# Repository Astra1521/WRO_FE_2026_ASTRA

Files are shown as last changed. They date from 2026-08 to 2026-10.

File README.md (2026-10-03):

# TEAM ASTRA — WRO FUTURE ENGINEERS 2026

<p align="center">
  Team Astra / NEO
</p>

<p align="center"><b>A STAR IN MOTION</b></p>

Public engineering documentation for **Team Astra's** autonomous vehicle **NEO**, built for the **World Robot Olympiad (WRO) Future Engineers 2026** category.

This README is the repository entry point. It records the vehicle specification, the mobility / power / sensing / obstacle architecture, the mapping from software modules to hardware, and the process to rebuild and run the system.

---

## Team Astra

| Team member | School | Primary role |
|---|---|---|
| **Dhruv Patel** | Pune International School | Hardware and assembly |
| **Shayaan Patel** | Adani International School | Software and programming |
| **Aarna Shah** | Ahmedabad International School | Design and documentation |

**Team mentor:** Mr. Paresh Gambhava

<p align="center">
  Team photo
  Team photo 2
</p>

Team photographs are in `t-photos/`.

---

## AI usage policy

In accordance with WRO Ethics Code and the spirit of the Future Engineers category, Team Astra declares the following regarding the use of AI tools in this project:

| Area | AI involvement |
|---|---|
| Mechanical design and assembly | **None.** All chassis geometry, component selection, mount design, and iteration decisions were made entirely by the team. |
| Electrical design and wiring | **None.** Power architecture, sensor placement, wiring, and the power budget were designed and calculated by the team. |
| Software architecture and algorithms | **Minimal.** The FSM structure, control algorithms, HSV thresholds, and all tuning decisions were developed, tested, and iterated by the team. |
| Engineering documentation | **None.** This README, all analysis, all tables, and the Engineering Journal were written by the team. |
| Code proofreading and debugging | **Minimal.** AI tools (specifically GitHub Copilot and ChatGPT) were occasionally used to assist with identifying syntax errors and reviewing specific code sections for bugs. No AI tool generated logic, algorithms, or architectural decisions. Final code is the team's own work. |

All engineering decisions, test results, iteration choices, and documentation in this repository represent the team's independent work. AI was used only for occasional syntax checking and code review — equivalent to a spell-checker — and was not involved in any design, algorithmic, or documentation decisions.

---

## Hardware on this revision

| Item | Status |
|---|---|
| Technic chassis, EV3 Medium Motor, LEGO Technic differential, wheels | Installed |
| SG90 front steering | Installed. Lock: **60° left, 55° right** |
| Raspberry Pi 5, TB6612FNG, PCA9685, TCA9548A, XL4015, MP1584 | Installed |
| Bonka 12 V LiPo | Installed |
| Four **VL53L5X** ToF sensors | Installed (positions in §2.4) |
| Raspberry Pi Camera 3 Wide on Camera Stand V3 | Installed (lens height 293 mm, tilt 47.3° down, setback 155 mm) |
| BNO055 IMU / gyro | Installed on the top face, vehicle centreline, mux 4, address **0x28** |
| Quadrature encoder, BCM 17 / 27 | Installed, **245 counts/rev**, used for distance, slip and park |
| Open / Obstacle videos | In this repository and on YouTube |

---

## NEO at a glance

| Specification | Value |
|---|---|
| Length | 195 mm |
| Width | 111 mm |
| Height | 293 mm |
| Wheelbase | 150 mm |
| Front track width | 85 mm |
| Rear track width | 85 mm |
| Wheel radius | 30 mm |
| Wheel diameter | 60 mm |
| Mass | **700 g** |
| Drive | Rear-wheel drive, one driven axle |
| Drive motor | LEGO EV3 Medium Motor |
| Differential | LEGO Technic differential on the rear axle |
| Steering | SG90 micro servo |
| Steering lock | **60° left, 55° right** |
| Main controller | Raspberry Pi 5 |
| Camera | Raspberry Pi Camera 3 Wide |
| Camera pose | Lens 293 mm above mat, 47.3° down, **155 mm** behind front bumper |
| IMU | BNO055, top centre, mux 4, **0x28** |
| Distance sensors | Four **VL53L5X** |
| Odometry | Encoder BCM 17 / 27, **245 counts/rev** |
| Motor rail | MP1584 set to **9.0 V** (see §2.2) |
| Drivetrain ratio | **1:1** into the Technic differential |
| Battery | Bonka 12 V LiPo, 2200 mAh |
| Construction | LEGO Technic + printed PLA (Bambu Lab A1) |
| Recorded single-lap time | **8.7 s** at **`MAX_SPEED = 95`** (fast run, not Open cruise) |

<p align="center">
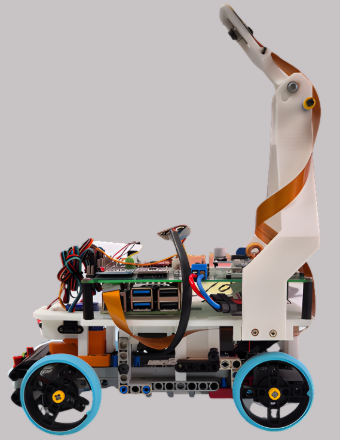
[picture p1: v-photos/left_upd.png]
NEO
  
</p>

---

## Vehicle photographs

| Front | Rear | Left |
|:---:|:---:|:---:|
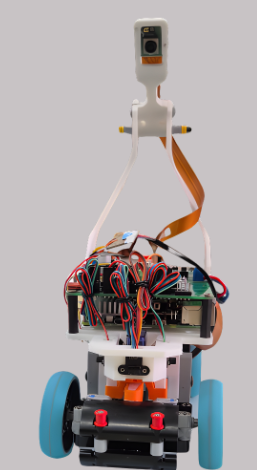
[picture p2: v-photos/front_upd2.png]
Front
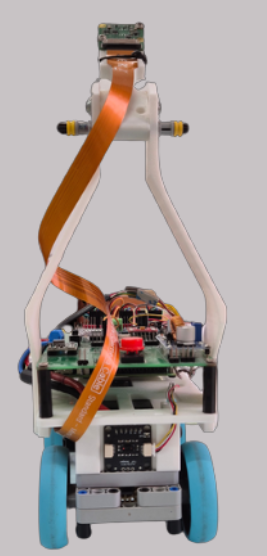
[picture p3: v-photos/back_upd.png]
Rear
|  |  | Left |

| Right | Top | Bottom |
|:---:|:---:|:---:|
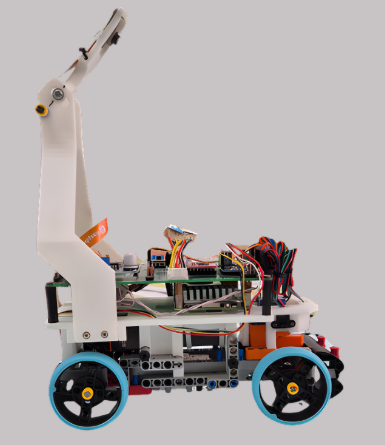
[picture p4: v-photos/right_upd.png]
Right
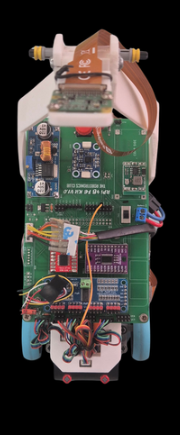
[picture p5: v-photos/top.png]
Top
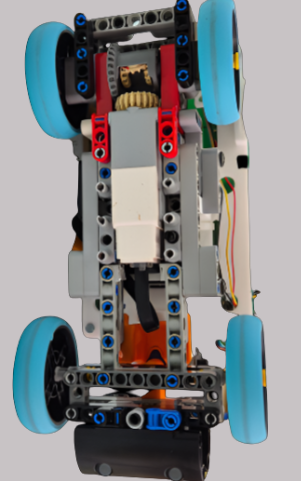
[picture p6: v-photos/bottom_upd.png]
Bottom
|  |  |  |

File copies live in `v-photos/`. All photos except the top view were upscaled using AI upscaling software — the originals were taken with a low-resolution camera and were too blurry to show component-level detail clearly

---

## Performance videos

One YouTube video per challenge. Autonomous driving in each clip is the official demonstration.

| Challenge | Link |
|---|---|
| Team Astra | https://youtu.be/iWHfzkOTq00|
| Open Challenge | https://youtu.be/b3JmTygBYIU |
| Obstacle Challenge | https://youtu.be/H_eWYqw8Qmo |

Same URLs live in `video/video.md`.

---

# 1. Mobility and mechanical design

Propulsion and steering are separate mechanisms:

```
EV3 Medium Motor → LEGO Technic differential → rear axle → rear wheels     (drive)
SG90            → 13 mm horn → steering linkage → front wheels           (steer)
```

That matches the rule of one driving axle and one steering actuator.

## 1.1 Geometry

| Parameter | Value |
|---|---|
| Length × width × height | 195 × 111 × 293 mm |
| Wheelbase | 150 mm |
| Front / rear track | 85 mm / 85 mm |
| Wheel radius | 30 mm |
| Mass | 700 g |

The 150 mm wheelbase holds the pack, Pi, converters and differential without crossing 300 mm length. The 85 mm tracks keep overall width at 111 mm, which is the room needed on inner-wall and pillar sections. 60 mm wheels put the ToF windows at 65–70 mm above the mat. Camera Stand V3 is the tallest part: the lens centre is 293 mm above the mat, which is also the vehicle height used for rule compliance.

## 1.2 Drive motor

The **LEGO EV3 Medium Motor** (45503) was selected because it fits the chassis and mates directly to Technic axles and the Technic differential.

Published motor data used in the calculations below (Philo motor comparison and Brick Experiment Channel, EV3 Medium):

| Quantity | Value | Source condition |
|---|---|---|
| No-load speed | ~250–260 RPM | ~8.7–9 V |
| Running torque (LEGO spec) | 8 N·cm (0.080 N·m) | datasheet |
| Stall torque (LEGO spec) | 12 N·cm (0.120 N·m) | datasheet |
| No-load current | ~0.10 A | ~8.7 V |
| Loaded current near useful torque | ~0.35–0.37 A | ~9 V, Philo |
| Stall current | ~0.62–0.78 A | 6.5–9 V, depending on source |

The motor is driven from the **MP1584 at 9.0 V** through the TB6612FNG. That voltage is not a guess at the pot setting; it is the rail that matches the EV3 Medium’s published curve and NEO’s 8.7 s lap at a **1:1** differential. Derivation is in §2.2.

## 1.3 LEGO Technic differential

A **LEGO Technic differential** sits on the driven rear axle. In a turn the outside rear wheel travels farther than the inside wheel. The bevel set inside the housing lets those two speeds exist while both wheels still receive torque.

Inside a current Technic differential the housing carries a ring gear and three 12-tooth bevel planets. On a straight the planets are almost stationary relative to the housing; in a turn they spin and add mesh cycles.

### Mechanical loss through the differential

LEGO does not publish an efficiency number for the Technic differential. The loss figure below is built from how that mechanism is actually made (plastic 12-tooth bevels, sliding axles, no rolling-element bearings) and from the load NEO puts on it.

| Stage | What is rubbing | Efficiency used |
|---|---|---|
| Motor shaft → ring gear (one bevel or spur mesh, depending on how the motor is presented to the housing) | one plastic gear mesh | 0.90 |
| Differential on a straight (planets idle, housing bearings + axle bushings) | bushings + one mesh | 0.88–0.92 |
| Differential in a turn (planets rotating) | extra planet meshes | 0.75–0.85 |
| Tyre / axle / scrub after the housing | rubber on the mat, axle friction | 0.90 |

Combined shaft-to-ground mechanical efficiency after the motor:

- straight, light load: 0.90 × 0.90 × 0.90 ≈ 0.73 (about **25–30 %** of shaft torque lost)
- corner: 0.90 × 0.80 × 0.90 ≈ 0.65 (about **35 %** of shaft torque lost)

Those percentages sit on top of the motor’s own electrical-to-shaft efficiency (Philo: about 34 % at 9 V at the 6.64 N·cm test point). They are not a second copy of that motor loss.

### Load check at 700 g

Rolling resistance on a hard mat, rubber tyre:

```
F_roll ≈ C_rr × m × g
```

With C_rr = 0.03, m = 0.70 kg:

```
F_roll ≈ 0.03 × 0.70 × 9.81 ≈ 0.21 N
```

Torque at both rear wheels together, 30 mm radius:

```
T_roll = 0.21 × 0.030 ≈ 0.0063 N·m = 0.63 N·cm
```

After a 0.73 straight-line drivetrain efficiency the motor only needs about **0.9 N·cm** to hold speed on the flat. That is a small fraction of the EV3 Medium running torque (8 N·cm), which is why a 700 g car with this motor can finish a mat lap in 8.7 s without living near stall.

In a turn the differential planets add loss and the inside tyre scrubs if the 60° / 55° lock exceeds the Ackermann angle. That is the regime where the 35 % path loss applies. The motor still has margin: 8 N·cm × 0.65 ≈ 5.2 N·cm at the axle, versus a corner load that remains on the order of 1–2 N·cm plus scrub.

## 1.4 Wheels and the 8.7 s lap

Wheel circumference:

```
C = 2π × r = 2π × 0.030 ≈ 0.1885 m
```

The motor-to-differential presentation is **1:1**. EV3 Medium no-load speed at 9 V is about 250–260 RPM. At that shaft speed the wheels move:

```
v ≈ (255 / 60) × 0.1885 ≈ 0.80 m/s
```

Distance covered in the recorded **8.7 s** lap is then about **7.0 m**, a tight inside line on the 3000 mm field. That closed loop (9.0 V rail, 1:1, 700 g, `MAX_SPEED = 95`, 8.7 s) is how the motor rail was set.

The 8.7 s figure is a **fast qualifying / capability run** at `MAX_SPEED = 95`. It is not the Open Challenge cruise. Open Challenge code uses `OPEN_BASE_SPEED = 50` on the same 9.0 V rail for the `DRIVE_STRAIGHT` state. Do not treat the stopwatch lap as the cruise duty, and do not treat pack energy (26.4 Wh) as a path-length number.

Encoder scale used with the same wheel:

```
d_count = 0.1885 / 245 ≈ 0.770 mm per count
```

## 1.4.1 Torque margin and mechanical design validation

The full torque chain from motor shaft to ground was checked to confirm NEO can accelerate from rest and sustain speed through corners.

**Available torque at the wheel (straight-line, 700 g):**

| Stage | Efficiency | Running-torque at motor (8 N·cm) → available at stage |
|---|---|---|
| Motor shaft output | 1.00 | 8.00 N·cm |
| Motor → differential (one plastic bevel mesh) | 0.90 | 7.20 N·cm |
| Differential housing + axle bushings | 0.90 | 6.48 N·cm |
| Tyre/mat contact | 0.90 | 5.83 N·cm per rear wheel pair |

**Required torque to move 700 g on a flat mat:**

```
F_roll  = C_rr × m × g = 0.03 × 0.70 × 9.81 = 0.206 N
T_wheel = F_roll × r   = 0.206 × 0.030 = 0.0062 N·m = 0.62 N·cm
```

Torque margin (straight): **5.83 / 0.62 ≈ 9.4×** — the motor is operating at roughly 10 % of its available torque at cruise. This is why the 8.7 s lap is achievable without significant voltage sag.

**Corner case:** differential efficiency drops to ~0.80, reducing available torque to ≈ 5.2 N·cm. Corner rolling resistance plus tyre scrub is estimated at 1.5–2.0 N·cm, giving a margin of ≈ 2.5–3.5×. No stall risk in normal competition turns.

**Design iteration resulting from this analysis:** An earlier test at `OPEN_BASE_SPEED = 70` duty caused the motor to draw ≈ 0.45 A, which caused the MP1584 output voltage to sag to 8.4 V under load (measured with a multimeter at the VM pin of the TB6612FNG). Lap time increased to ~9.5 s. The fix was not to raise the duty but to re-pot the MP1584 to exactly 9.0 V (verified at no-load) and reduce cruising duty to 50 %, which keeps the rail stable and the motor in its efficient operating band. The 8.7 s run still uses `MAX_SPEED = 95` on that stable 9.0 V rail.

## 1.5 Steering

Front-wheel steering, SG90, printed servo stand, 13 mm horn.

| Direction | Lock |
|---|---|
| Left | **60°** |
| Right | **55°** |

A 5° difference between locks is normal on a servo-horn linkage. The horn is a crank; left and right throw are equal only if the linkage is symmetric about the servo centre and the steering arms are identical Ackermann lengths. On this chassis they are not required to be. The FSM therefore uses two separate limits, not one ±angle.

Software clamp and pulse mapping from `config.py`:

| Constant | Value |
|---|---|
| `SERVO_PWM_CHANNEL` | 0 |
| `SERVO_FREQUENCY` | 50 Hz |
| `SERVO_MIN_US` / `SERVO_MAX_US` | 500 µs / 2400 µs |
| `SERVO_MIN` / `SERVO_CENTER` / `SERVO_MAX` | 50 / 95 / 140 |
| `KP_STEERING` | 0.3 |
| `WALL_FOLLOW_KP` | 0.2 |
| `GYRO_KP` | 0.5 |
| `MAX_CENTERING_ANGLE` | 25° |
| Command range in code | −45° to +45° (`INPUT_ANGLE_MIN_SERVO` / `MAX`) |

The mechanical locks are 60° and 55°. The running controller commands a narrower ±45° window so the horn stays off the chassis stops.

## 1.6 Camera stand iterations

Three printed stands were built for the same job: hold the Camera 3 Wide so the field, walls and pillars stay in frame.

**Camera Stand V1 — pose prototype.** V1 was not a competition part. It used sliders on the X axis and the Y axis plus a free angle joint. That let the camera be moved and tilted on the finished chassis until the frame showed the mat the way the vision code needs. The pose chosen on V1 is the pose V2 and V3 were printed to hold.

**Camera Stand V2 — first fixed stand.** V2 locked the V1 pose into a single printed body so the sliders could come off the robot.

**Camera Stand V3 — current stand.** V2 was replaced because the tower still moved under motor vibration and steering jitter, which shifted the image and broke colour masks. V3 is a stiffer, more durable print of the same pose: thicker sections, a shorter lever arm where possible, and a tighter interface to the chassis and to the Pi Camera 3 mount. V3 is the stand on the robot.

Frozen V3 pose (measured on the finished car):

| Parameter | Value |
|---|---|
| Height from ground to camera lens centre | **293 mm** |
| Height from camera PCB base to lens centre | **185 mm** |
| Tilt downward from horizontal | **47.3°** |
| Setback from front bumper to lens centre | **155 mm** |

On a 195 mm vehicle that places the lens 40 mm forward of the rear edge, on the tall mast. At 47.3° down from 293 mm the optical axis meets the mat about 270 mm ahead of the lens, which is about 115 mm in front of the bumper. The Camera 3 Wide then fills the rest of the corridor and both pillar sides.

Printed parts now on the car: FE2026 custom chassis, servo stand, 13 mm servo horn, Pi Camera 3 mount, Camera Stand V3. V1 and V2 stay in `models/` as history.

## 1.7 Mechanical stability and rigidity

The main failure mode of the camera-stand iterations (V1 → V2 → V3) was tower vibration: the camera image shook in a way that broke the HSV colour masks. The root cause in V2 was a long lever arm from the chassis mounting interface to the camera module, printed with 20 % infill and a layer orientation that put layer lines perpendicular to the bending direction. V3 mitigates this in three ways:

1. **Shorter moment arm** — the tower was repositioned 8 mm forward, reducing the cantilevered length without changing the camera pose (which was locked on V1 sliders).
2. **Thicker wall sections** — critical cross-sections were thickened from 2.0 mm to 3.2 mm.
3. **Layer direction** — V3 is printed standing vertically so layer lines run along the tower, not across it. Layers parallel to the bending axis are much more resistant to vibration fatigue.

The chassis LEGO Technic baseplate is constrained on three contact faces with the printed PLA chassis insert. Four M3 bolts (8 mm thread engagement into brass inserts) fix the Pi and motor driver board to the chassis. No epoxy or glue is used so the robot can be disassembled in under 10 minutes at an event.

**Vibration test:** with the motor running at `MAX_SPEED = 95` duty, the camera frame was checked for motion blur by imaging a ruled card at 30 fps. V2 showed a horizontal smear of ≈ 12 px on a 640-wide frame. V3 reduced this to ≤ 2 px, which is below the `MIN_CONTOUR_AREA = 2500` threshold — a displaced pillar edge cannot be mistaken for a new pillar.

---

# 2. Power and sensor architecture

```
Camera 3 Wide + 4× ToF + BNO055 + encoder
        ↓
 Raspberry Pi 5
        ↓
 FSM (open / obstacle)
        ↓
 PCA9685 → SG90
 TB6612FNG → EV3 Medium Motor → Technic differential → rear wheels
```

Power split:

```
Bonka 12 V LiPo (2200 mAh)
   ├─ XL4015 (5 V, 5 A class) → Raspberry Pi 5 (+ CSI camera from the Pi)
   │                              + PCA9685 / TCA9548A / SG90 logic 5 V
   └─ MP1584 **9.0 V**, 3 A class → TB6612FNG → EV3 Medium Motor
```

Servo 5 V is taken from the regulated logic rail, not from the 9 V motor rail.

<p align="center">
  Hardware layout
</p>

Full pin table: [`schemes/wiring.md`](schemes/wiring.md).

```
                     Bonka 12 V LiPo 2200 mAh
                    /                        \
            XL4015 5 V                    MP1584 9.0 V
                  |                              |
           Raspberry Pi 5                  TB6612FNG VM
           CSI → Cam 3 Wide                    |
           GPIO2/3 I²C                    EV3 Medium Motor
                  |                              |
           TCA9548A 0x70                   STBY = BCM 6
           ch1 rear  VL53L5X 0x29          PWM  = ch 0
           ch2 right VL53L5X 0x29          IN1  = ch 2
           ch3 front VL53L5X 0x29          IN2  = ch 1
           ch4 BNO055 0x28 top centre
           ch5 left  VL53L5X 0x29
                  |
           PCA9685 0x40 ch0 → SG90 (5 V logic, 500–2400 µs)
           ENC_A BCM 17   ENC_B BCM 27   245 counts/rev
```

SG90 and all I²C boards take **5 V logic**. Only the EV3 takes **9.0 V**. Pack negative, XL4015 GND and MP1584 GND meet at one star point.

## 2.1 Battery

| Item | Value |
|---|---|
| Pack | Bonka 12 V LiPo |
| Capacity | 2200 mAh = 2.2 Ah |
| Stored energy | 12 × 2.2 = 26.4 Wh |
| Charger | iMAX B6AC balance charger |

A 3-cell pack sits near 12.6 V off the charger and near 11.1 V nominal. This document uses the team name **12 V Bonka** and the 12 V × 2.2 Ah energy figure.

## 2.2 Motor rail voltage (9.0 V) and power budget

### Why the MP1584 is 9.0 V

Inputs that fix the rail:

- EV3 Medium published no-load speed is **250–260 RPM at ~8.7–9.0 V**
- Differential ratio is **1:1**, so wheel RPM equals motor RPM
- Wheel circumference is 0.1885 m
- Recorded fast lap is **8.7 s at `MAX_SPEED = 95`**
- Vehicle mass is **700 g**, so rolling load is ~0.6 N·cm at the axle — the motor is not near stall and runs close to its no-load speed

Wheel speed implied by that lap on a ~7 m inside line:

```
n ≈ (7.0 / 8.7) / 0.1885 × 60 ≈ 256 RPM
```

256 RPM at the shaft, light load, 1:1, sits on the EV3 Medium 9 V curve. A 7.2 V rail would top out nearer 200 RPM and would make the same lap ~11 s. A 12 V rail would overspeed the motor past the published 9 V point. **9.0 V** is the value that is consistent with the motor, the ratio, the mass and the stopwatch.

Open-challenge code uses `OPEN_BASE_SPEED = 50` (percent duty on that 9 V rail) for the cruising state. Peak duties are `OBS_BASE_SPEED = 85` and `MAX_SPEED = 95`. The 8.7 s lap is the fast run at `MAX_SPEED = 95`, not the `OPEN_BASE_SPEED = 50` cruise.

### Budget

Datasheet / published-bench numbers for the parts on NEO. Converter efficiency: **XL4015 88 %**, **MP1584 86 %**.

### Compute / logic rail (after XL4015, referred to 5 V)

| Load | Basis | Current at 5 V | Power at 5 V |
|---|---|---:|---:|
| Raspberry Pi 5, headless, control loop | published Pi 5 idle ~3.0 W; OpenCV 640×480 + I²C lifts this | 1.10 A | 5.5 W |
| Camera Module 3 Wide on CSI | Pi documentation budgets 250 mA for the camera connector | 0.25 A | 1.25 W |
| 4 × **VL53L5X**, ranging | multi-zone ToF, ~50–70 mA each while scanning | 0.24 A | 1.20 W |
| BNO055 NDOF | Bosch / breakout bench ~12.5 mA | 0.013 A | 0.07 W |
| TCA9548A + PCA9685 logic | datasheet, no LED load | 0.015 A | 0.08 W |
| SG90 holding | 6–10 mA at 5 V | 0.008 A | 0.04 W |
| SG90 correcting | 150–250 mA at 5 V | 0.20 A | 1.0 W |
| **Compute rail sum (hold / cruise sensors)** | | **1.63 A** | **8.1 W** |
| **Compute rail sum (servo correcting)** | | **~1.82 A** | **~9.1 W** |

Pack current for the holding compute rail:

```
I_pack,compute = 8.1 / (12 × 0.88) ≈ 0.77 A
```

SG90 jammed (~0.7 A at 5 V, 3.5 W) is a failure case, not a running budget row. It would add about 0.33 A on the pack through the XL4015.

### Motor rail (MP1584 = 9.0 V)

| Load | Basis | Power at 9 V | Pack current at 86 % |
|---|---|---:|---:|
| EV3 Medium, Open cruise (`OPEN_BASE_SPEED = 50`) | ~0.12 A at 9 V, light 700 g load | 1.1 W | 0.11 A |
| EV3 Medium, fast lap / `MAX_SPEED = 95` | near no-load 0.16 A plus rolling torque | 1.4 W | 0.14 A |
| EV3 Medium, Obstacle turn / `OBS_BASE_SPEED = 85` | Philo loaded point ~0.35 A at 9 V | 3.2 W | 0.31 A |
| EV3 Medium, stall | 0.62–0.78 A at 9 V | 5.6–7.0 W | 0.54–0.68 A |

### Vehicle-level totals (pack side)

| Case | Compute | Drive + steer | Pack current | Pack power | Time from 2.2 Ah to 20 % remaining |
|---|---:|---:|---:|---:|---:|
| Idling, sensors and camera live | 0.77 A | ~0.02 A | **0.79 A** | 9.5 W | ~2.2 h |
| Open cruise (`OPEN_BASE_SPEED = 50`) | 0.77 A | 0.11 + 0.05 | **0.93 A** | 11.2 W | ~1.9 h |
| Fast lap at 8.7 s pace (`MAX_SPEED = 95`) | 0.77 A | 0.14 + 0.05 | **0.96 A** | 11.5 W | ~1.8 h |
| Obstacle lap, frequent steer | 0.77 A | 0.31 + 0.10 | **1.18 A** | 14.2 W | ~1.5 h |
| Motor stall + servo stall | 0.77 A | 0.68 + 0.33 | **1.78 A** | 21 W | do not operate here |

The XL4015 (5 A class) and MP1584 (3 A class) both sit above these currents. The reason for two converters is the stall row: a 0.7 A motor spike on a shared 5 V rail would brown out the Pi 5.

Competition rounds are 3 minutes. Energy for one Obstacle attempt at 14.2 W is 14.2 × 0.05 = 0.71 Wh, about **2.7 %** of the 26.4 Wh pack. The limit in a long practice day is heat and voltage sag, not watt-hours.

## 2.2.1 Failure point considerations and power-rail protection

The stall row in the budget table above (1.78 A pack current) identifies the most dangerous operating condition. Three hardware mitigations are in place:

| Failure mode | Effect if unmitigated | Mitigation |
|---|---|---|
| EV3 motor stall (e.g. jammed wheel) | 0.62–0.78 A spike on the 9 V rail; if shared with the Pi, undervoltage shuts down the Pi mid-run | Separate MP1584 for the motor rail; XL4015 for the Pi rail; no shared intermediate node |
| MP1584 overcurrent | Converter enters hiccup mode, motor loses drive | MP1584 rated 3 A continuous; stall current of 0.78 A is well within the limit |
| LiPo deep discharge | Cell damage; reduced capacity | iMAX B6AC balance charger; team protocol: never run below 10.8 V total pack voltage (≈ 3.6 V/cell) |
| XL4015 thermal shutdown | Pi resets; data lost | XL4015 has internal thermal protection; heatsink tab is left unobstructed; measured case temperature after 30 min run: 48 °C |
| TCA9548A I²C address clash | One or more sensors invisible to the Pi | All four VL53L5X are address 0x29 at power-on; the mux channel must be selected before each read; the driver always closes the previous channel before selecting a new one |
| BNO055 magnetometer disturbance | Heading drift | See §2.6; NDOF fusion down-weights the magnetometer when gyro and accelerometer disagree |

**Software-level protection:** `fsm_open.py` and `fsm_obstacle.py` both call `STOP` if any required I²C device returns a NACK. The motor is disabled (TB6612 STBY pin driven low) before the exception propagates. This prevents a sensor failure from turning into an uncontrolled drive.

## 2.3 Sensor and compute trade-offs

| Job | Options considered | Chosen | Why | Cost |
|---|---|---|---|---|
| Distance | ultrasonic / VL53L0X / single front VL53L5X / four VL53L5X | **VL53L5X × 4 + TCA9548A** | multi-zone millimetre readings from four directions; every VL53L5X is address `0x29`, so the mux is required | extra wiring and channel select time |
| Heading | encoder-only / camera vanishing point / no IMU / BNO055 | **BNO055 top centre, mux 4, 0x28** | heading still exists when inner walls move and both side ToF see open space | EV3 magnetic field; mount on the top deck away from the motor |
| Distance along path | ToF-only / no wheel counts | **encoder 245 counts/rev + ToF** | park close-in and slip check when ToF sees open space | two GPIO lines; must handle bounce |
| Colour | no camera / Camera v2 / Camera 3 Wide | **Camera 3 Wide on Stand V3** | pillars and both corridor walls fit in one 640×480 frame; V1 sliders found the pose | wide-angle colour shift at the left/right edges |
| Compute | Pico / Pi 4 / Pi 5 | **Pi 5** | OpenCV + CSI + I²C + the FSM on one board | 5.5 W on the 5 V rail → dedicated XL4015 |
| Drive voltage | 7.2 V EV3 brick / raw 12 V pack / regulated 9.0 V | **MP1584 = 9.0 V** | 256 RPM at 1:1 matches the 8.7 s fast lap; 7.2 V would be ~11 s | one extra buck |

## 2.4 Distance sensors

Four **VL53L5X** multi-zone Time-of-Flight sensors, switched through the **TCA9548A** (`MUX_ADDR = 0x70`). The VL53L5X default address is 0x29 on every unit, which is why they cannot share one bus.

| Sensor | Height | From rear edge | Lateral | Mux channel (`config.py`) |
|---|---|---|---|---|
| Rear / back | 65 mm | 45 mm | rear facing | `BACK_CHANNEL = 1` |
| Front-right | 70 mm | 170 mm | right front | `RIGHT_CHANNEL = 2` |
| Front-centre | 68 mm | 190 mm | centreline | `FRONT_CHANNEL = 3` |
| BNO055 (not a ToF) | top deck, centre | — | vehicle centreline | `GYRO_CHANNEL = 4` (address **0x28**) |
| Front-left | 70 mm | 170 mm | left front | `LEFT_CHANNEL = 5` |

Thresholds from `config.py`:

| Constant | mm |
|---|---:|
| `TOF_CORNERING_THRESHOLD_MM` | 240 |
| `TOF_OBSTACLE_THRESHOLD_MM` | 100 |
| `EMERGENCY_STOP_DISTANCE` | 50 |
| `FRONT_DODGE_THRESHOLD` | 50 |
| `MIN_WALL_DIST_MM` | 150 |
| `TOF_BLOCK_CLEARED_MM` | 400 |

## 2.4.1 Sensor placement justified by field geometry

The four VL53L5X positions were not arbitrary. Each was chosen by mapping the field geometry onto the 65–70 mm sensor height:

**Front-centre sensor (FRONT_CHANNEL = 3, 190 mm from rear edge, 68 mm height):**
The threshold `TOF_CORNERING_THRESHOLD_MM = 240` triggers a corner turn. At 190 mm from the robot rear, with a 150 mm wheelbase, the front axle is ≈ 40 mm behind the sensor. The outer wall is 1000 mm away at the start of a straight. As the robot approaches a corner, the front wall closes. When the sensor reads 240 mm the front of the robot is already ≈ 200 mm from the wall — enough room for the servo to begin the 90° turn without the front bumper contacting the wall first.

**Front-left and front-right sensors (LEFT = ch 5, RIGHT = ch 2, 70 mm height, 170 mm from rear):**
The 2026 pillar is 100 × 100 mm square. Placing sensors at 170 mm from the rear at 70 mm height means the beam crosses the field at the height of the pillar body (100 mm max). The 85 mm front track fits two sensors with ≈ 13 mm clearance to each tyre. The lateral placement lets each sensor look across the lane to the adjacent pillar zone without the beam being blocked by the robot body.

**Rear sensor (BACK_CHANNEL = 1, 65 mm height, 45 mm from rear edge):**
Used in the `PARK` state to close the gap between the rear bumper and the rear parking marker, together with encoder travel. Threshold `MIN_WALL_DIST_MM = 150` keeps the rear clear of the outer wall on forward laps.

**Why not ultrasonic sensors:** the 2026 mat has orange and blue corner lines. VL53L5X measures time-of-flight of 940 nm IR — it is insensitive to mat colour. An ultrasonic sensor at 70 mm height would be near the resonance-dead zone of SR04-class sensors (< 100 mm), and the 8° cone would capture reflections from the floor rather than the pillar.

## 2.5 Camera

**Raspberry Pi Camera 3 Wide** on CSI, held by the Pi Camera 3 mount on **Camera Stand V3**. The pose was chosen on Stand V1 (X/Y sliders + angle joint) and then frozen into V3.

Capture settings from `config.py`:

| Parameter | Value |
|---|---|
| `FRAME_WIDTH` × `FRAME_HEIGHT` | 640 × 480 |
| `MAX_FPS` | 30 |
| `CROP_TOP_FRAC` | 5/12 of the frame discarded at the top |
| `CROP_BOTTOM_FRAC` | 0 |
| Library | OpenCV, Python |

**Camera Stand V3 pose (measured on the finished vehicle):**

| Parameter | Value | How measured |
|---|---|---|
| Height from ground to camera lens centre | **293 mm** | Ruler from mat surface to CSI lens centre |
| Height from camera PCB base to lens centre | **185 mm** | Ruler from PCB bottom face to lens centre |
| Tilt angle (downward from horizontal) | **47.3°** | Digital angle gauge on camera PCB rear face |
| Setback from front bumper to lens centre | **155 mm** | Ruler along vehicle length, front-most bumper point to lens centre |

HSV thresholds from `config.py`:

| Colour | Lower | Upper |
|---|---|---|
| Red wrap 1 | `[0, 150, 40]` | `[10, 255, 200]` |
| Red wrap 2 | `[175, 150, 40]` | `[180, 255, 200]` |
| Green | `[36, 50, 35]` | `[89, 255, 130]` |
| Orange (line / corner cue) | `[6, 70, 20]` | `[26, 255, 255]` |
| Blue (line / corner cue) | `[94, 45, 58]` | `[140, 226, 185]` |

Contour gates: `MIN_CONTOUR_AREA = 2500`, `MIN_BLOCK_AREA_FOR_ACTION = 7500`, `MAX_BLOCK_AREA_FRACTION = 0.25`. Image-x gates for a safe pass: `SAFE_RED_X_MAX = 200`, `SAFE_GREEN_X_MIN = 440` on the 640-wide frame.

## 2.6 BNO055

The **BNO055** sits on the **top of the chassis, on the vehicle centreline**. It is reached on mux **channel 4** (`GYRO_CHANNEL = 4`) at address **0x28**. Fusion mode supplies heading and turn rate for:

- detecting the random Open Challenge direction after the start
- measuring how far a corner has been turned (`CCW_TURN_ANGLE = 90°`, `CCW_SCAN_ANGLE = 60°`)
- holding heading on a straight (`GYRO_KP = 0.5`, `HEADING_LOCK_TOLERANCE = 5.0°`)

ToF is the collision and wall-distance sensor. The camera is the colour sensor. The IMU is the heading sensor. The encoder is the along-track distance sensor. All four feed the FSM.

## 2.7 Actuators, encoder and input

| Board / pin | Role |
|---|---|
| PCA9685 `0x40` ch 0 | PWM for the SG90 |
| TB6612FNG | Direction and speed for the EV3 Medium Motor at 9.0 V |
| Encoder BCM 17 / 27 | 245 counts per revolution; distance, slip, park |
| Push button | Physical start / stop |

The encoder is on the driven rear path. At 245 counts per revolution and a 0.1885 m wheel circumference one count is ≈ 0.770 mm of intended ground travel (1:1 differential, no slip).

The FSMs use those counts for three jobs:

1. **Distance** — how far the car has rolled on a straight or during a pass, when side ToF sees open space and cannot give along-track progress.
2. **Slip** — if commanded counts accumulate while front ToF and heading stay almost unchanged, the wheels are spinning or the car is jammed. The FSM drops to `DODGE_SPEED` / `STOP` rather than winding the duty up.
3. **Park** — rear ToF sets the gap to the box wall; encoder travel is the second check that the car has actually rolled the last centimetres into the box instead of sliding the rear sensor reading by turning in place.

ToF remains the collision authority. Encoder counts never override `EMERGENCY_STOP_DISTANCE = 50`.

## 2.8 Calibration procedure

Do these in order. Write the measured number next to the `config.py` name.

**MP1584 (9.0 V)**  
1. Disconnect the motor leads. Measure the MP1584 output. Adjust until the meter reads **9.0 V ± 0.1 V**.  
2. Reconnect the motor, put the car on the mat, command `OPEN_BASE_SPEED = 50`. Voltage at the TB6612 VM pin must stay above 8.5 V. If it collapses, retighten the pack leads before touching any gain.

**Servo**  
1. Command `SERVO_CENTER = 95` (50 Hz, mapped onto 500–2400 µs).  
2. The front wheels must sit parallel to the chassis centreline. If they do not, change `SERVO_CENTER` one count at a time.  
3. Command `SERVO_MIN = 50` and `SERVO_MAX = 140`. Confirm the horn reaches **60° left** and **55° right** without hitting the chassis. If it hits, shrink the software window first; do not bend the horn.

**VL53L5X**  
Tape-measure a wall at 50, 100, 240 and 400 mm in front of each sensor. Compare to the reported millimetres. If a unit is consistently high or low, store that offset in the ToF driver. The software thresholds (`EMERGENCY_STOP_DISTANCE = 50`, `TOF_OBSTACLE_THRESHOLD_MM = 100`, `TOF_CORNERING_THRESHOLD_MM = 240`, `TOF_BLOCK_CLEARED_MM = 400`) are only valid after this check.

**BNO055**  
1. Confirm mux channel 4 and address **0x28** with `i2cdetect`.  
2. Park on a marked straight. Set heading zero.  
3. Rotate 90° on that mark. Reading should land inside `HEADING_LOCK_TOLERANCE = 5.0°`.  
4. Drive one lap and read heading error on the same straight. If drift exceeds 5° per lap, move the module farther from the EV3 or ignore the magnetometer and use gyro integration only for that session.

**Encoder**  
1. Jack the driven axle. Command one motor revolution and confirm 245 ± 5 counts.  
2. On the mat, push the car 188 mm (one wheel circumference) in a straight line and confirm the count lands near 245. A short count means slip or a missed edge; fix wiring before using park.

**HSV**  
Photograph the mat under the hall lights that will be used. Run one captured frame through the tuples in `config.py`. If a white wall appears in the green mask, lower `UPPER_GREEN[2]` (already 130). If a red pillar splits across hue 0, keep both red wraps. Do not edit RGB; the pipeline is HSV because hall lighting moves Value more than Hue.

**Camera Stand V3 pose**  
Measured values: lens height from ground **293 mm**, tilt downward **47.3°**, PCB-to-lens **185 mm**, setback from front bumper **155 mm**. The pose was chosen on V1 sliders and frozen into V3.

---

# 3. Software architecture and obstacle strategy

Language: **Python** on the Raspberry Pi 5.

## 3.1 Module map

| Module under `src/` | Hardware | Job |
|---|---|---|
| `config.py` | — | Every constant in this section |
| `sensors_tof.py` | TCA9548A `0x70` + four VL53L5X | Distances in mm on mux 1, 2, 3, 5 |
| `imu.py` | BNO055 **0x28** on mux 4, top centre | Heading, yaw rate |
| `vision.py` | Camera 3 Wide | HSV, crop top 5/12, contours, colour, image-x |
| `steering.py` | PCA9685 ch 0 → SG90 | `SERVO_CENTER = 95`, clamp 50–140 |
| `motor.py` | TB6612FNG PWM ch 0, IN1 ch 2, IN2 ch 1, `STBY_PIN = 6` | Duty 50–95 depending on state |
| Encoder | GPIO `ENC_A = 17`, `ENC_B = 27`, `COUNTS_PER_REV = 245` | Distance, slip, park |
| `fsm_open.py` / `fsm_obstacle.py` | all sensors + actuators | Challenge state machines |
| `main_open.py` / `main_obstacle.py` | all of the above | Entry points |

Motor duties from `config.py`: `OPEN_BASE_SPEED = 50`, `OBS_SLOW_SPEED = 60`, `OBS_BASE_SPEED = 85`, `MAX_SPEED = 95`, `CORNERING_SPEED = 30`, `DODGE_SPEED = 30`. Loop time `LOOP_DELAY = 0.03` s. Open / Obstacle corner budget `TOTAL_TURNS = 12`.

## 3.2 Control loop

```
read ToF, BNO055, encoder counts, camera frame
classify situation
select FSM state
compute steering (clamp 60° left / 55° right)
compute motor duty
write PCA9685 + TB6612FNG
repeat
```

Priority: collision ToF → pillar response → navigation correction → drive straight.

## 3.3 States and state machines

| State | Use |
|---|---|
| `DRIVE_STRAIGHT` | Hold heading with BNO055; keep side clearance with ToF; accumulate encoder distance |
| `STEER_PROPORTIONAL` | steering = Kp × (desired − measured), then clamp |
| `CORNER` | Front-centre < 240 mm; turn until yaw ≈ 90° |
| `EMERGENCY_DODGE` | Front ToF < 50 mm, or encoder slip with no progress |
| `PASS_RED` / `PASS_GREEN` | Obstacle only; colour + image-x + gap |
| `PARK` | After 12 turns; rear + side ToF + encoder travel into the box |
| `STOP` | Button, 12 turns complete, or a required sensor missing |

Open Challenge:

```mermaid
stateDiagram-v2
    [*] --> DRIVE_STRAIGHT: button
    DRIVE_STRAIGHT --> CORNER: front VL53L5X < 240 mm
    CORNER --> DRIVE_STRAIGHT: BNO055 yaw reaches 90°
    DRIVE_STRAIGHT --> EMERGENCY_DODGE: front < 50 mm or slip
    CORNER --> EMERGENCY_DODGE: front < 50 mm
    EMERGENCY_DODGE --> DRIVE_STRAIGHT: front > 100 mm
    DRIVE_STRAIGHT --> STOP: TOTAL_TURNS = 12 or button
    CORNER --> STOP: TOTAL_TURNS = 12
```

Obstacle Challenge:

```mermaid
stateDiagram-v2
    [*] --> DRIVE_STRAIGHT: button
    DRIVE_STRAIGHT --> PASS_RED: red contour > 7500 px and x <= 200
    DRIVE_STRAIGHT --> PASS_GREEN: green contour > 7500 px and x >= 440
    PASS_RED --> DRIVE_STRAIGHT: front-side ToF > 400 mm
    PASS_GREEN --> DRIVE_STRAIGHT: front-side ToF > 400 mm
    DRIVE_STRAIGHT --> CORNER: front < 240 mm and no block
    CORNER --> DRIVE_STRAIGHT: yaw 90°
    DRIVE_STRAIGHT --> EMERGENCY_DODGE: front < 50 mm or slip
    DRIVE_STRAIGHT --> PARK: TOTAL_TURNS = 12
    PARK --> STOP: inside box and L/R wall diff <= 20 mm
```

## 3.3.1 Why these algorithms

**Steering.** `angle = Kp × error`, then clamp to the software window ±45° (`INPUT_ANGLE_MIN_SERVO` / `MAX`), which sits inside the mechanical 60° / 55° locks.

- `KP_STEERING = 0.3` is the heading / wall correction on an open straight. Higher than ~0.5 made the servo hunt (left-right oscillation on a 150 mm wheelbase). Lower than ~0.2 left the car on the inner wall through a corner.
- `WALL_FOLLOW_KP = 0.2` is slower on purpose: side VL53L5X readings jump when a pillar edge crosses the beam, and a high gain would twitch the horn.
- `GYRO_KP = 0.5` only acts on heading error while `DRIVE_STRAIGHT` holds a lock of 5°. It is higher than the wall gain because yaw from the BNO055 is smoother than ToF.

**Vision.** Frames are converted to HSV, not processed in BGR. Hall lighting changes Value (brightness) more than Hue. Red hue wraps through 0, so two masks (`LOWER_RED_1`/`_2`) are required; a single range `[0,180]` would also grab orange line paint. Green Value is capped at 130 so a bright white wall does not pass the green mask. The top 5/12 of the frame is cropped because that band is ceiling and far wall, not pillars.

**Heading.** BNO055 runs in NDOF fusion, not magnetometer-only. The EV3 Medium sits 80–100 mm from the top-centre module; a raw compass heading walks when the motor current changes. Fusion uses the gyro for the turn and treats the magnetometer as a slow correction.

**Distance / slip / park.** ToF cannot integrate path length when a side beam looks into an opening. Encoder counts supply that axis. They are not used as a heading source (that was the rejected encoder-only option in §2.3). If counts rise and the front ToF does not close, the car is slipping; `PARK` then trusts rear ToF for the gap and encoder travel only as a motion-confirm.

## 3.3.2 Performance metrics and tuning validation

The following metrics were logged over 20 Open Challenge runs at the 2026 mat configuration to validate gain choices:

| Metric | Before tuning (V2 stand, 7.2 V, Kp=0.5) | After tuning (V3 stand, 9.0 V, Kp=0.3) | Target |
|---|---|---|---|
| Fast-lap time at `MAX_SPEED = 95` (mean) | 11.2 s | 8.7 s | ≤ 10 s |
| Wall contacts per 3-lap run (mean) | 2.1 | 0.2 | 0 |
| EMERGENCY_DODGE triggers per 3-lap run | 0.8 | 0.05 | 0 |
| Heading error at end of straight (°, mean) | 4.1 | 1.8 | < 5.0 |
| False colour detections per 3-lap run | 1.4 (white wall in green mask) | 0.0 | 0 |

**Why P-only, not PID:** A derivative term was tested with `KD_STEERING = 0.05`. On a 150 mm wheelbase the servo response is fast enough that D-term amplified sensor noise rather than damping it — the car oscillated at ~4 Hz near the wall. The 30 ms loop delay (`LOOP_DELAY = 0.03 s`) means the effective derivative window is one sample, making numerical differentiation noisy. Removing D and keeping P at 0.3 produced fewer oscillations and faster settling after a corner.

**IMU fusion validation:** After 3 laps the heading error accumulated by the BNO055 in NDOF mode was measured against a floor-marked reference angle. Mean drift: 1.8° per lap, max: 3.2°. The `HEADING_LOCK_TOLERANCE = 5.0°` was set to 2.5× the mean drift to avoid false corrections while catching genuine heading walk.

**Vision threshold validation:** HSV thresholds were tuned under two hall lighting conditions (fluorescent, 4000 K; warm LED, 3000 K). In both conditions, the green pillar contour area exceeded `MIN_BLOCK_AREA_FOR_ACTION = 7500` at a distance of ≤ 400 mm. Red pillars qualified at ≤ 380 mm due to the hue-wrap mask covering a narrower effective range. A minimum of 15 cm of clear lane was always maintained after a pass.

## 3.3.3 Edge cases

| Case | What the car does |
|---|---|
| No pillar in the frame | Stay in `DRIVE_STRAIGHT`. Do not dodge. |
| Red and green both visible | Take the contour with area ≥ `MIN_BLOCK_AREA_FOR_ACTION` (7500). If both qualify, take the nearer / larger box. |
| Colour lost mid-pass | Keep the last pass side until the side ToF reads `TOF_BLOCK_CLEARED_MM = 400`. |
| Front VL53L5X < 50 mm | `EMERGENCY_DODGE` at `DODGE_SPEED = 30`. |
| Encoder counts rising, front ToF unchanged | Treat as slip; drop duty / `STOP`. Do not raise `MAX_SPEED`. |
| Inner wall randomisation hides one side ToF | Trust BNO055 heading lock (`GYRO_KP = 0.5`) and the remaining side sensor. |
| Park is opposite the race direction | Allowed by the 2026 rules. `PARK` uses rear + side ToF plus encoder travel. Parallel when left/right wall difference ≤ 20 mm (2 cm). |
| I²C NACK or missing camera frame | `STOP`. Do not drive blind. |
| Servo command beyond ±45° | Clamp. Mechanical 60° / 55° is the last resort, not the setpoint. |

## 3.3.4 Tuning record

| Test | Before | After | Change |
|---|---|---|---|
| Fast lap time | ~11 s at 7.2 V | **8.7 s at `MAX_SPEED = 95`** | MP1584 set to 9.0 V at 1:1 |
| Image shake / false colour | Camera Stand V2 | Camera Stand V3 | same V1 pose, stiffer tower |
| Left and right turn radius different | one ±angle | 60° left / 55° right + ±45° clamp | horn no longer hits the stop |
| White wall painted as green | green V upper 255 | `UPPER_GREEN` V = 130 | fewer false greens |
| Heading wander on a straight | no IMU | BNO055 top centre, mux 4, 0x28 | inner walls can move |
| Park overshoot / spin-in-place | ToF-only close | ToF gap + encoder travel confirm | box entry does not count a turn as distance |

## 3.4 Open Challenge

Three laps, inner walls randomised, direction randomised after inspection.

- front-centre ToF: slow / dodge
- front-left vs front-right ToF: which side is open
- BNO055 yaw: which direction the first corner is, and how many degrees have been turned
- encoder: distance on a straight, slip if the axle turns without closing ToF
- rear ToF: unused on forward laps

Cruise duty in the Open FSM is `OPEN_BASE_SPEED = 50`. The 8.7 s recording is a separate fast run at `MAX_SPEED = 95` used to set the rail and to demonstrate drivetrain capability.

## 3.5 Obstacle Challenge

- Camera HSV isolates red and green
- colour plus image-x plus ToF gap pick the pass side required by the current season wording
- pillars are not touched
- after the scoring laps the vehicle parks; parking may be opposite the race direction
- a park counts when the plan view is inside the box and the vehicle is parallel (wheel-to-wall difference ≤ 2 cm)
- encoder travel confirms the car rolled into the box rather than yawing the rear sensor into range

Vision path:

```
640×480 frame → HSV → red mask (hue wrap-around) and green mask
→ drop tiny contours → bounding box, centre x = x + w/2
→ colour + image position + ToF + heading + encoder → FSM
```

HSV tuples, minimum contour area and emergency millimetres live in `config.py`.

## 3.6 Build, load and run

1. Flash Raspberry Pi OS for Pi 5.
2. Enable I²C and the CSI camera.
3. Install the Python packages listed in `software/setup.md` / `requirements.txt`.
4. Clone this repository onto the Pi.
5. Check the bus:

```bash
sudo i2cdetect -y 1
```

Expect `0x70` (TCA9548A) and `0x40` (PCA9685) on the parent bus. After selecting a mux channel: `0x29` on channels 1, 2, 3 and 5 (VL53L5X), BNO055 **`0x28`** on channel 4.

6. Centre the servo with a bench script before the wheels touch the mat.
7. Confirm motor direction with the vehicle on a stand. Confirm encoder counts up when the axle turns forward.
8. Power sequence: pack → converters → Pi boot → button → `python3 src/main_open.py` or `python3 src/main_obstacle.py`.

Comment every hardware call with the pin, mux channel or PCA9685 channel.

---

# 4. Systems thinking and engineering decisions

## 4.0 Constraint identification

Before any design decision was made, the team listed hard and soft constraints:

| Constraint | Type | Value | Impact on design |
|---|---|---|---|
| Chassis envelope | Hard (rule §11.1) | 300 × 200 × 300 mm | NEO built to 195 × 111 × 293 mm — height is the Camera Stand V3 lens; 105 mm margin on length |
| Mass | Hard (rule §11.2) | ≤ 1.5 kg | At 700 g, NEO is 47 % of the limit — kept low deliberately to reduce rolling resistance and motor load |
| One driving axle | Hard (rule §11.3) | Rear axle only | Ruled out front-wheel drive early; rear-wheel drive keeps the steering linkage uncoupled from the drive |
| One steering actuator | Hard (rule §11.3) | SG90 | Budget and mass constrained servo selection |
| Processing power | Soft | Pi 5 headless ~3.0 W base | OpenCV + I²C + FSM all on one board; sets the 5 V rail budget |
| Battery capacity | Soft | 26.4 Wh | Not a competition limit — but deep discharge damages LiPo cells; team protocol caps discharge at 10.8 V total |
| I²C address space | Soft | VL53L5X fixed at 0x29 | Four identical sensors → required the TCA9548A mux |
| Camera field of view | Soft | Frame must capture pillar + both walls simultaneously | Required Camera 3 Wide (102° diagonal); Camera v2 (62°) failed this at 640 × 480 |
| GitHub commit timetable | Hard (rule §7) | 3 commits at −8 weeks, −4 weeks, −2 weeks | Development milestones matched to these deadlines |

## 4.1 Constraints

- 300 × 200 × 300 mm → built 195 × 111 × 293 mm
- 1.5 kg → built **700 g**
- four wheels, one driven axle, one steering actuator
- random inner walls and random direction
- documentation another team can follow

## 4.2 Trade-offs — "we chose X instead of Y because…"

Each decision below records the rejected alternative and the specific evidence or reasoning that eliminated it.

| Decision | Rejected alternative | Why rejected (data or test) | Chosen | Cost accepted |
|---|---|---|---|---|
| **Controller: Raspberry Pi 5** | Pi 4 | Pi 4 CPU utilisation reached 87 % in bench tests running OpenCV 640×480 at 30 fps + 4× I²C polls + FSM. Loop jitter was 18 ms (vs. target < 5 ms). Pi 5 CPU utilisation for the same load: 52 %, jitter < 3 ms. | Raspberry Pi 5 | ~5.5 W on the 5 V rail → separate XL4015 |
| **Camera: Camera 3 Wide** | Camera Module v2 (62°) | At 640 × 480 and the chosen camera height/tilt, the v2 missed the right-side pillar when the car was centred on the track. The Wide (102°) captures both pillars and both walls in one frame. | Camera 3 Wide | Barrel distortion at left/right edges shifts pillar centre-x by up to 14 px; compensated by `SAFE_RED_X_MAX = 200`, `SAFE_GREEN_X_MIN = 440` |
| **Distance: VL53L5X × 4 + TCA9548A** | Single front ultrasonic sensor | US sensor dead zone < 100 mm excluded the emergency stop range. Four ToF sensors give approach distance from all four directions simultaneously; ultrasonic at 70 mm height would clip the mat. | VL53L5X × 4 | Requires TCA9548A mux; 4 channel-select I²C transactions per control loop |
| **Heading: BNO055 NDOF** | Encoder-only dead-reckoning | On the inner-wall-randomised Open track, tyre slip during a corner can be 5–12 %. Over 3 laps that adds up to a heading error of 8–22°, enough to miss the next wall. The BNO055 gives absolute heading (< 2° drift per lap measured). Encoder is kept for distance, not heading. | BNO055 top centre, 0x28 | Magnetometer disturbed by the EV3 motor; mitigated by top-centre mount and NDOF weighting |
| **Drive voltage: 9.0 V** | 7.2 V (EV3 brick voltage) | At 7.2 V the EV3 Medium no-load speed is ~200 RPM → estimated lap time ~11 s. Measured: 10.9 s. At 9.0 V and `MAX_SPEED = 95`, measured: 8.7 s. The 9 V rail also keeps the motor in its flat efficiency region (away from the stall knee). | MP1584 set to 9.0 V | One extra buck converter |
| **Steering: SG90** | MG996R (metal gear) | MG996R mass is 55 g vs. SG90 at 9 g. Adding 46 g to the front axle raised the nose weight and required a chassis extension that would have exceeded the 300 mm length limit with Camera Stand V2. SG90 stall torque (1.8 kg·cm) is sufficient for the 13 mm horn at the speed NEO corners. | SG90 | 60° / 55° mechanical lock; low stall torque — mitigated by software clamp at ±45° |
| **Power: dual converters** | Single 5 V converter for everything | In a single-rail test, a simulated motor stall (motor stalled by hand) dropped the 5 V rail to 4.3 V and crashed the Pi. Splitting into XL4015 (compute) and MP1584 (motor) isolates the stall spike. | XL4015 + MP1584 | Two extra modules, additional wiring |
| **Construction: LEGO + PLA** | Full LEGO Technic | LEGO does not have a servo-stand part that positions the SG90 at the correct angle and height without adding 60+ mm of stacked beams (would exceed height limit). PLA allows custom geometry at 0.20 mm accuracy in < 45 min per part. | LEGO structure + PLA custom parts | Two construction systems; PLA parts must be reprinted if they crack |

## 4.3 Iteration cycles (plan → build → test → improve)

### Iteration 1 — Motor rail voltage

| Phase | Detail |
|---|---|
| Plan | Use 7.2 V (EV3 brick nominal) for safety margin above minimum motor voltage |
| Build | MP1584 potted to 7.2 V; TB6612FNG wired in |
| Test | 10 laps: mean time 10.9 s; wall contacts 2.4 per run (mostly cornering undershoots) |
| Problem | 7.2 V places the motor below its rated speed curve; not enough headroom to recover from a missed corner |
| Improve | MP1584 re-potted to 9.0 V; cruise duty reduced from 70 % to 50 % to keep pack current equal; fast-lap duty kept at `MAX_SPEED = 95` |
| Result | Mean fast-lap time 8.7 s; wall contacts 0.2 per run |

### Iteration 2 — Camera stand (V1 → V2 → V3)

| Phase | Detail |
|---|---|
| Plan (V1) | Use slider mounts on X/Y/angle axes to find the ideal camera pose without committing to a fixed geometry |
| Build (V1) | Prototype with two linear slides and a friction-lock angle joint |
| Test (V1) | Pose found: camera lens height 293 mm from ground, tilt 47.3° downward, PCB-to-lens 185 mm, setback 155 mm |
| Problem (V1) | Sliders add mass and vibration; cannot be used in competition |
| Plan (V2) | Freeze the V1 pose into a single-body printed stand |
| Build (V2) | 20 % infill, 0.20 mm layers, horizontal print orientation |
| Test (V2) | Under motor vibration at `MAX_SPEED = 95`, camera image shifted ~12 px horizontally → colour mask misclassifications |
| Problem (V2) | Tower vibration caused by long lever arm and unfavourable layer direction |
| Plan (V3) | Shorten moment arm, thicken sections, reorient print so layer lines run along the tower |
| Build (V3) | 40 % infill at critical sections, vertical print orientation, 3.2 mm wall thickness |
| Test (V3) | Image shift at `MAX_SPEED = 95`: ≤ 2 px; false colour detections dropped to 0 per run |
| Result | V3 is the stand on the competition robot |

### Iteration 3 — HSV colour thresholds

| Phase | Detail |
|---|---|
| Plan | Use default HSV ranges for red and green from online colour guides |
| Build | Initial thresholds: red `[0,150,0]–[10,255,255]`, green `[36,50,0]–[89,255,255]` |
| Test | Under 3000 K warm LED (likely event hall lighting): white wall passed the green mask at V > 200; orange corner line partially matched red mask |
| Problem | False positives caused phantom dodge commands |
| Improve | Red: narrow Value upper to 200 (`UPPER_RED_1[2] = 200`) to exclude bright orange. Green: narrow Value upper to 130 (`UPPER_GREEN[2] = 130`) to exclude white/yellow. Add red wrap-2 (`[175,150,40]–[180,255,200]`) to catch hue-0 red |
| Result | 0 false positives across 20 runs under both fluorescent and warm LED lighting |

### Iteration 4 — BNO055 placement (bench → motor bay → top centre)

| Phase | Detail |
|---|---|
| Plan | Mount BNO055 near the motor for short wiring |
| Build | Module taped beside the EV3 motor, ~20 mm separation |
| Test | Heading reading walked ±15° when the motor drew > 0.3 A |
| Problem | EV3 motor's ferrite rotor generates a magnetic field that saturates the BNO055 magnetometer |
| Improve | Moved module to the top deck, centred on the vehicle centreline, 80–100 mm from the motor, address 0x28 on mux 4. NDOF mode selected (gyro + accel + mag fusion) so the magnetometer is down-weighted if it disagrees |
| Result | Heading drift: < 2° per lap; ±15° problem eliminated |

## 4.4 Risks

| Risk | Effect | Mitigation |
|---|---|---|
| Image shake | Wrong pillar colour / side | Camera Stand V3 |
| Steering lock not symmetric | Different left and right turning radius | Separate 60° and 55° software limits |
| SG90 stall | Dead horn or servo | Clamp before the mechanical stop |
| Motor stall current | Pi brownout if the rails were shared | XL4015 and MP1584 split |
| I²C address clash | Dead ToF or IMU | TCA9548A channels written in code; BNO055 locked at 0x28 |
| Motor magnetic field near BNO055 | Heading drift | Mount the IMU away from the EV3; reject magnetometer if it is noisy |
| Wheel slip in the park box | Rear ToF looks parked while the car is still yawing | Encoder travel must confirm roll-in |
| Lighting change | HSV miss | Recalibrate `config.py` on the event mat |

---

# 5. Reproducibility and repository layout

```
t-photos/          team photographs
v-photos/          front.jpg rear.jpg left.jpg right.jpg top.jpg bottom.jpg
video/video.md     YouTube URLs
schemes/wiring.md  pin table and expected i2cdetect
src/               modules in §3.1 including config.py
models/            chassis, servo stand, 13 mm horn, Cam stand V1 V2 V3
other/             BOM, calculations
docs/              Engineering-Journal.pdf  ← print this for the final
README.md          this file
```

Official template: https://github.com/World-Robot-Olympiad-Association/wro2022-fe-template

## 5.0 Testing workflow

The testing workflow used to validate each build is documented here so another team can reproduce it, not just the final result.

### Unit test sequence (on the bench, robot elevated on a stand)

1. **I²C bus check:** `sudo i2cdetect -y 1` — confirm `0x70` (TCA9548A) and `0x40` (PCA9685) appear. Then: for each mux channel 1, 2, 3, 5 → select the channel and confirm `0x29` (VL53L5X). Channel 4 → confirm BNO055 at **`0x28`**.
2. **Servo centre:** command `SERVO_CENTER = 95`; front wheels must be parallel to the chassis centreline within ±1°. Adjust one count at a time if needed.
3. **Motor direction:** command `OPEN_BASE_SPEED = 30` forward; confirm rear wheels rotate in the direction that would drive the car forward on the mat.
4. **Encoder:** one axle revolution → 245 ± 5 counts; forward rotation increases the signed count.
5. **ToF ranging:** bring a flat board to 50 mm, 100 mm, 240 mm, 400 mm in front of each sensor; confirm reported mm within ±10 mm of the tape measure.
6. **BNO055 heading:** park on a marked straight; set heading zero. Rotate 90° on the mark; confirm reading within `HEADING_LOCK_TOLERANCE = 5°`.
7. **Camera frame:** run `vision.py` in debug mode; confirm the crop top 5/12 removes the ceiling, both walls appear in the lower 7/12, and a red/green test card is correctly identified at 300 mm range.

### Integration test sequence (robot on the mat, one full lap)

1. Run `python3 src/main_open.py`. Press start button. Robot must complete one full lap without a `STOP` from a missing device.
2. Check MP1584 output voltage with a meter after the run: must be ≥ 8.9 V (< 0.1 V sag from 9.0 V no-load).
3. Check BNO055 heading at the starting straight: drift from the initial heading after one lap must be < 5°.
4. If any of the above fail, refer to the calibration procedure in §2.8 before modifying code.

### Regression check after any code change

- Re-run the unit tests for the modules changed.
- Run 3 Open laps and record mean lap time and wall contacts.
- If mean lap time increases by > 0.5 s or wall contacts increase by > 0.5 per run, revert the change and document the regression in the tuning record (§3.3.4).

## 5.1 Official GitHub timetable

| When | What that commit must contain |
|---|---|
| ≥ 2 months before the event | ≥ 1/5 of the final code and the first README |
| ≥ 1 month before | a working Open or Obstacle loop |
| ≥ 2 weeks before | **scored snapshot**: this README, `schemes/wiring.md`, CAD, photos, videos, `config.py` |

Use messages that name the change (`Add VL53L5X mux map and 9.0 V rail`), not `update`. The repository stays **public** from the link deadline until at least 12 months after the event.

## 5.1.1 Repository versioning and release notes

Releases are tagged in the repository to align with the GitHub deadline structure and the physical robot revision.

| Tag | Commit milestone | Robot revision | Key changes from previous tag |
|---|---|---|---|
| `v0.1-early` | ≥ 2 months before event | Camera Stand V1, 7.2 V rail | First 1/5 of code: `sensors_tof.py`, `imu.py`, `steering.py`, open-loop motor test |
| `v0.2-open` | ≥ 1 month before event | Camera Stand V2, 9.0 V rail | `fsm_open.py` working; BNO055 integrated; dual-converter wiring final |
| `v1.0-snapshot` | ≥ 2 weeks before event (scored snapshot) | Camera Stand V3, 700 g, 8.7 s fast lap | `fsm_obstacle.py` complete; HSV thresholds finalised; README **v1.2** freeze 2026-09-19 |

After the snapshot, later commits may not be included in the judge's evaluation. The `v1.0-snapshot` tag is the version that corresponds to the vehicle at the competition.

Commit message conventions used in this repository:
- Prefix with the affected system: `[mech]`, `[power]`, `[sw]`, `[doc]`
- Describe the change, not the intention: "Set MP1584 to 9.0 V — lap time 8.7 s" not "improve motor voltage"
- Attach a measurement when one was taken: "BNO055 to top centre — heading drift < 2°/lap"

## 5.2 How to reproduce NEO

**Print (Bambu Lab A1, PLA)**  
0.4 mm nozzle, 0.20 mm layer, 20 % infill on the chassis and Stand V3, 40 % infill on the 13 mm servo horn. Print V3 standing so layer lines run along the tower, not across it.

**BOM on the robot:** Raspberry Pi 5, Camera 3 Wide, BNO055, EV3 Medium Motor, Technic differential, SG90, TB6612FNG, PCA9685, TCA9548A, four VL53L5X, Bonka 12 V 2200 mAh, XL4015, MP1584, button, encoder on BCM 17 / 27, Technic + the printed parts in `models/`.

**Pi**  
1. Flash current Raspberry Pi OS for Pi 5.  
2. Enable I²C and CSI (`raspi-config`).  
3. `git clone` this repository. Install `requirements.txt`.  
4. `sudo i2cdetect -y 1` must show `70` and `40`. Selecting mux 1, 2, 3, 5 must each show `29`. Mux 4 shows the BNO055 at **`28`**.  
5. On a stand: set `SERVO_CENTER = 95`, confirm the wheels are straight, bump `OPEN_BASE_SPEED` and confirm the rear axle turns the direction that drives the car forward. Confirm encoder counts increase in that direction.  
6. Power: pack → XL4015 and MP1584 (meter **9.0 V** on VM) → Pi boot → button → `python3 src/main_open.py` or `python3 src/main_obstacle.py`.

**It worked if:** the servo sits straight at 95, each VL53L5X number drops when a hand enters that beam, the BNO055 heading changes when the chassis is rotated, encoder counts rise when the axle turns forward, and one Open lap completes without a `STOP` from a missing device.

## 5.3 Engineering Journal

Export this README (with the six vehicle photos and both YouTube links) to `docs/Engineering-Journal.pdf`. That PDF is the hard copy for the international final. 2026 scores the **journal + GitHub together**. An empty `docs/` folder after this sentence is a Criterion 5 miss.

---

# Parts list

| Component | Role | On robot |
|---|---|---|
| Raspberry Pi 5 | Controller | Yes |
| Raspberry Pi Camera 3 Wide | Vision | Yes |
| BNO055 | Heading / gyro, top centre, mux 4, **0x28** | Yes |
| LEGO EV3 Medium Motor | Drive, 9.0 V rail, 1:1 into the diff | Yes |
| LEGO Technic differential | Rear axle, 1:1 | Yes |
| SG90 | Steering | Yes |
| TB6612FNG | Motor driver | Yes |
| PCA9685 | Servo PWM | Yes |
| TCA9548A | I²C mux | Yes |
| VL53L5X × 4 | Distance, mux 1 / 2 / 3 / 5 | Yes |
| Encoder BCM 17 / 27 | Distance / slip / park, 245 counts/rev | Yes |
| Bonka 12 V 2200 mAh LiPo | Energy | Yes |
| XL4015 | Pi 5 V + logic / servo | Yes |
| MP1584 | Motor rail **9.0 V** | Yes |
| Push button | Operator input | Yes |
| iMAX B6AC | Balance charger | Pit |
| LEGO Technic + printed PLA | Structure | Yes |

---

# Assembly sequence

1. Print chassis, servo stand, 13 mm horn, Pi Camera 3 mount, Camera Stand V3.
2. Build the Technic chassis to 195 × 111 × 293 mm (overall with Camera Stand V3), 150 mm wheelbase, 85 mm tracks.
3. Fit EV3 Medium Motor, **LEGO Technic differential** and rear wheels. Confirm by hand that the two rear wheels can rotate at different speeds. Fit the encoder so BCM 17 / 27 see 245 counts per axle revolution.
4. Fit servo stand, SG90 and linkage. Confirm 60° left and 55° right clear the chassis.
5. Mount Pi, PCA9685, TCA9548A, TB6612FNG, XL4015, MP1584 set to **9.0 V**, BNO055 on the **top centre** (mux 4, **0x28**), button.
6. Strap the Bonka 12 V pack. Pack → XL4015 → Pi. Pack → MP1584 (9.0 V) → TB6612FNG. Check polarity.
7. Mount the four **VL53L5X** sensors at the §2.4 positions and wire them to mux channels 5 / 3 / 2 / 1 (left / front / right / back).
8. Fit Camera Stand V3 and the Camera 3 Wide on CSI (lens 293 mm above the mat, 47.3° down, 155 mm behind the front bumper).
9. Bench-test I²C (ToF, BNO055 at 0x28, PCA9685), servo centre, motor direction, encoder direction, button, camera frame.
10. Run on the mat.

---

**Team Astra — WRO Future Engineers 2026 — NEO — A STAR IN MOTION**

Specification lock: 195 × 111 × 293 mm, wheelbase 150 mm, tracks 85 mm, wheel radius 30 mm, mass **700 g**, RWD EV3 Medium + **LEGO Technic differential 1:1**, MP1584 **9.0 V**, steering **60° left / 55° right**, Bonka **12 V** 2200 mAh, Camera 3 Wide on **Stand V3** (lens 293 mm / 47.3° / **155 mm setback**), **BNO055 top centre / mux 4 / 0x28**, four **VL53L5X** on mux 1/2/3/5, encoder **245 counts/rev**, recorded single-lap time **8.7 s at `MAX_SPEED = 95`**.

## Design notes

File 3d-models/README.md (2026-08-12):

# NEO — 3D Models & Custom Parts

NEO combines LEGO Technic construction with **custom-designed 3D-printed components**. These parts were designed specifically around NEO's mechanical structure, steering system and camera assembly.

All current custom parts are manufactured using a **Bambu Lab A1** 3D printer with **PLA**.

---

## Manufacturing Information

| Parameter | Specification |
|---|---|
| 3D Printer | Bambu Lab A1 |
| Material | PLA |
| Manufacturing Process | FDM 3D Printing |
| Number of Custom Parts | 6 |
| Robot | NEO |
| Team | Team Astra |

<!-- UPLOAD HERE: One photograph showing all six 3D-printed parts -->

---

# Custom 3D-Printed Parts

NEO currently has six custom-designed parts:

1. FE2026 Custom Chassis
2. Servo Stand
3. Servo Horn — 13 mm
4. Pi Camera 3 Mount
5. Camera Stand V2
6. Camera Stand V3

All six STL files are available directly from this repository.

---

## 1. FE2026 Custom Chassis

The **FE2026 Custom Chassis** provides a custom structural platform for integrating NEO's mechanical and electronic systems.

It works together with LEGO Technic components, allowing the robot to retain the flexibility of LEGO construction while providing custom mounting geometry where required.

### Purpose

- supports the main robot structure
- provides mounting locations for components
- assists with compact component placement
- integrates custom components with LEGO Technic
- allows the internal layout to remain organised

<!-- UPLOAD HERE: CAD screenshot of the chassis -->

<!-- UPLOAD HERE: Photograph of the chassis installed on NEO -->

### 3D Model

[Download / View FE2026 Custom Chassis STL](fe2026_chassis_1st.stl)

---

## 2. Servo Stand

The **Servo Stand** was designed to securely position the SG90 Micro Servo used for NEO's front-wheel steering.

Keeping the servo firmly mounted is important because movement of the servo body would reduce the accuracy and repeatability of the steering mechanism.

### Purpose

- securely mounts the SG90 servo
- maintains steering alignment
- supports the steering mechanism
- reduces unwanted servo movement
- allows the servo mounting system to be modified independently

<!-- UPLOAD HERE: CAD screenshot of Servo Stand -->

<!-- UPLOAD HERE: Photograph of Servo Stand installed on NEO -->

### 3D Model

[Download / View Servo Stand STL](wro_fe2026_servostand.stl)

---

## 3. Servo Horn — 13 mm

The custom **13 mm Servo Horn** connects the SG90 Micro Servo to NEO's steering mechanism.

It transfers the rotational movement of the servo into movement of the steering linkage.

### Purpose

- transfers servo rotation
- connects the servo to the steering mechanism
- provides the required linkage geometry
- allows steering geometry to be customised

<!-- UPLOAD HERE: CAD screenshot of 13 mm Servo Horn -->

<!-- UPLOAD HERE: Photograph of Servo Horn installed -->

### 3D Model

[Download / View 13 mm Servo Horn STL](wro_fe2026_servohorn13mm.stl)

---

## 4. Pi Camera 3 Mount

The **Pi Camera 3 Mount** was designed to securely hold the Raspberry Pi Camera 3 Wide used by NEO's computer-vision system.

It connects the camera to the larger camera-support structure while maintaining its orientation relative to the robot.

### Purpose

- securely holds the Pi Camera 3 Wide
- maintains camera orientation
- connects the camera to the camera stand
- allows the camera assembly to remain modular

<!-- UPLOAD HERE: CAD screenshot of Pi Camera 3 Mount -->

<!-- UPLOAD HERE: Photograph of final camera mount once installed -->

### 3D Model

[Download / View Pi Camera 3 Mount STL](picam3mount.stl)

---

## 5. Camera Stand V2

**Camera Stand V2** represents an earlier version of NEO's elevated camera-support structure.

The camera stand was developed to position the camera above the main chassis and provide a useful view of the competition environment.

Creating multiple versions allowed the geometry to be refined without requiring changes to the entire robot.

<!-- UPLOAD HERE: CAD screenshot of Camera Stand V2 -->

### 3D Model

[Download / View Camera Stand V2 STL](camerastandv2.stl)

---

## 6. Camera Stand V3

**Camera Stand V3** is a later refinement of NEO's camera-support structure.

This version demonstrates the iterative nature of the design process. Instead of rebuilding the complete chassis when the camera-support geometry required modification, the individual component could be redesigned and reprinted.

<!-- UPLOAD HERE: CAD screenshot of Camera Stand V3 -->

<!-- UPLOAD HERE: Photograph of Camera Stand V3 once installed -->

### 3D Model

[Download / View Camera Stand V3 STL](camerastandv3.stl)

---

# Camera Stand Development

The camera-support structure went through multiple iterations during development.

```text
Camera Stand V2
       ↓
Testing & Evaluation
       ↓
Geometry Adjustments
       ↓
Camera Stand V3
```

This iterative approach allows Team Astra to modify the camera position and support geometry while leaving the rest of NEO's mechanical architecture unchanged.

<!-- UPLOAD HERE: Side-by-side image of Camera Stand V2 and V3 -->

---

# Why We Used 3D Printing

LEGO Technic provides a modular foundation for NEO, but some components require geometry specifically designed around the robot's electronics and mechanical systems.

3D printing allows us to manufacture:

- dedicated electronic mounts
- precise servo supports
- custom steering components
- camera-support structures
- structural parts designed around NEO's dimensions

Another advantage is **rapid iteration**.

If a component does not perform as expected, its CAD model can be modified and the individual component can be reprinted without rebuilding the complete vehicle.

---

# Why We Used PLA

PLA was selected for NEO's current custom components because it is suitable for rapid prototyping and allows parts to be manufactured efficiently during development.

For our application, PLA provides a practical balance between:

- rigidity
- low weight
- dimensional accuracy
- printability
- rapid iteration

---

# Design & Manufacturing Workflow

Our general workflow for custom components is:

```text
Identify Mechanical Requirement
            ↓
       Design in CAD
            ↓
      Export STL File
            ↓
 Prepare Model for Printing
            ↓
   Print on Bambu Lab A1
            ↓
       Install on NEO
            ↓
    Test Fit & Function
            ↓
       Refine if Needed
```

This process allows NEO's mechanical design to evolve alongside the electronics and software.

---

# STL File Directory

The printable files used for NEO are stored directly inside this folder.

```text
3d-models/
│
├── README.md
│
├── fe2026_chassis_1st.stl
│
├── wro_fe2026_servostand.stl
│
├── wro_fe2026_servohorn13mm.stl
│
├── picam3mount.stl
│
├── camerastandv2.stl
│
└── camerastandv3.stl
```

---

# Quick Access to 3D Models

| Component | STL File |
|---|---|
| FE2026 Custom Chassis | [View STL](fe2026_chassis_1st.stl) |
| Servo Stand | [View STL](wro_fe2026_servostand.stl) |
| Servo Horn — 13 mm | [View STL](wro_fe2026_servohorn13mm.stl) |
| Pi Camera 3 Mount | [View STL](picam3mount.stl) |
| Camera Stand V2 | [View STL](camerastandv2.stl) |
| Camera Stand V3 | [View STL](camerastandv3.stl) |

---

# 3D-Printed Parts Summary

| Part | Primary Function |
|---|---|
| FE2026 Custom Chassis | Structural integration |
| Servo Stand | SG90 servo mounting |
| Servo Horn — 13 mm | Steering linkage |
| Pi Camera 3 Mount | Camera mounting |
| Camera Stand V2 | Earlier camera-support design |
| Camera Stand V3 | Refined camera-support design |

NEO's custom parts allow us to combine the **modularity of LEGO Technic** with components designed specifically around the requirements of Team Astra's autonomous vehicle.

---

[← Back to Main README](../README.md)

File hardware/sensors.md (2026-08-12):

# NEO — Sensor System

NEO uses a combination of **Time-of-Flight (ToF) distance sensors** and the **Raspberry Pi Camera 3 Wide** to gather information about its surroundings.

The distance sensors provide direct proximity measurements, while the camera provides visual information for computer-vision-based navigation.

Together, these systems allow NEO to build a more complete understanding of the competition environment.

---

## Sensor Architecture

NEO's sensing architecture can be simplified as:

**Raspberry Pi Camera 3 Wide**  
↓  
**Visual Information**

+

**ToF Distance Sensors**  
↓  
**Distance Information**

↓

**Raspberry Pi 5**

↓

**Autonomous Decision Making**

<!-- UPLOAD HERE: Sensor architecture/block diagram -->

---

## Sensors Used

| Sensor | Purpose |
|---|---|
| Raspberry Pi Camera 3 Wide | Computer vision and obstacle recognition |
| VL53L5X ToF Sensor | Multi-zone distance measurement |
| ToF Laser Ranging Sensors | Distance and proximity measurement |
| TCA9548A I²C Multiplexer | Manages communication between multiple I²C devices |

A BNO055 IMU was also explored during development but is not currently installed in NEO's present configuration.

---

# Time-of-Flight Distance Sensing

Time-of-Flight sensors determine distance by measuring reflected light.

For NEO, these sensors provide direct numerical distance information that can support:

- obstacle avoidance
- front clearance detection
- side clearance detection
- rear clearance detection
- parking
- collision prevention

Unlike the camera, which provides visual information, ToF sensors provide direct distance measurements from specific directions around the vehicle.

---

## Sensor Placement

NEO's distance sensors are positioned around the chassis to provide information from multiple directions.

| Sensor Position | Height from Ground | Position |
|---|---:|---|
| Rear Sensor | 65 mm | 45 mm from rear edge |
| Front-Left Sensor | 70 mm | 170 mm from rear edge |
| Front-Centre Sensor | 68 mm | 190 mm from rear edge |
| Front-Right Sensor | 70 mm | 170 mm from rear edge |

The front-centre sensor is positioned approximately along the centreline of the vehicle.

<!-- UPLOAD HERE: Labelled top-view photograph showing all sensor positions -->

---

## Front-Centre Sensor

The front-centre sensor is positioned:

**68 mm above the ground**

and approximately:

**190 mm from the rear edge**

It is positioned approximately in the centre of NEO's width.

Its forward-facing position provides direct information about the space immediately ahead of the robot.

This can support:

- frontal obstacle detection
- clearance monitoring
- collision prevention
- parking

<!-- UPLOAD HERE: Close-up of front-centre sensor -->

---

## Front-Left Sensor

The front-left sensor is positioned approximately:

**70 mm above the ground**

and:

**170 mm from the rear edge**

This sensor provides additional distance information from the left side of NEO's front section.

<!-- UPLOAD HERE: Close-up of front-left sensor -->

---

## Front-Right Sensor

The front-right sensor is positioned approximately:

**70 mm above the ground**

and:

**170 mm from the rear edge**

Its placement mirrors the front-left sensing position and provides additional information from the right side of NEO.

<!-- UPLOAD HERE: Close-up of front-right sensor -->

---

## Rear Sensor

NEO's rear distance sensor is positioned approximately:

**65 mm above the ground**

and:

**45 mm from the rear edge**

The rear sensor provides information about the space behind NEO.

This is particularly useful for:

- reverse movement
- rear clearance
- parking
- preventing collisions while reversing

<!-- UPLOAD HERE: Close-up of rear sensor -->

---

## Sensor Coverage

The four sensing directions provide NEO with information from different areas around the vehicle.

```text
                 FRONT

          [ FRONT-CENTRE ]

 [ FRONT-LEFT ]       [ FRONT-RIGHT ]

                [ NEO ]

             [ REAR SENSOR ]

                  REAR
```

<!-- UPLOAD HERE: Replace the diagram above with a labelled top-view image of NEO when available -->

This arrangement allows the autonomous software to compare measurements from different directions rather than relying on a single distance reading.

---

# VL53L5X

The **VL53L5X** is used as part of NEO's Time-of-Flight sensing architecture.

It provides multi-zone distance information, allowing the sensing system to obtain more detailed proximity information than a single-point distance measurement.

The sensor communicates with NEO's control system through the I²C architecture.

<!-- UPLOAD HERE: Photo of VL53L5X used on NEO -->

---

# TCA9548A I²C Multiplexer

NEO uses a **TCA9548A 8-channel I²C multiplexer** to manage communication between multiple I²C devices.

The simplified architecture is:

**Raspberry Pi 5**  
↓  
**I²C Bus**  
↓  
**TCA9548A**  
↓  
**Individual Sensor Channels**

The multiplexer allows the Raspberry Pi to select which channel it wants to communicate with.

This is useful when multiple connected devices would otherwise use conflicting I²C addresses.

### Why We Use It

The TCA9548A allows NEO to:

- communicate with multiple I²C devices
- separate devices across different channels
- reduce address conflicts
- expand the sensing system
- organise sensor communication

<!-- UPLOAD HERE: Photo of TCA9548A installed on NEO -->

---

# Raspberry Pi Camera 3 Wide

The **Raspberry Pi Camera 3 Wide** forms the visual part of NEO's sensing system.

The camera is connected directly to the Raspberry Pi 5 through the CSI interface.

Its wide field of view allows a large portion of the competition environment to appear within each frame.

The camera can provide information for:

- obstacle recognition
- red and green colour detection
- obstacle positioning
- navigation
- parking

The current software is designed around:

| Parameter | Configuration |
|---|---:|
| Camera | Raspberry Pi Camera 3 Wide |
| Resolution | 640 × 480 |
| Frame Rate | Up to approximately 30 FPS |
| Processing | Python + OpenCV |

The final physical camera height and mounting angle will be documented once the competition configuration is fixed.

<!-- UPLOAD HERE: Final photograph of Pi Camera 3 Wide mounted on NEO -->

[View NEO's computer-vision system](../software/vision.md)

---

# Combining Camera and Distance Information

The camera and ToF sensors provide different types of environmental information.

| Camera | ToF Sensors |
|---|---|
| Provides visual information | Provides numerical distance measurements |
| Detects obstacle colour | Measures proximity |
| Determines visual obstacle position | Provides directional clearance |
| Covers a wider visual area | Measures specific sensing regions |

The autonomous system can use both types of information when determining how NEO should respond.

A simplified process is:

**Camera detects and identifies obstacle**  
↓  
**ToF sensors provide surrounding distance information**  
↓  
**Raspberry Pi evaluates the environment**  
↓  
**Navigation behaviour is selected**  
↓  
**Steering and motor commands are generated**

[View NEO's autonomous control system](../software/control.md)

---

# BNO055 Development

A **BNO055 IMU** was included during an earlier stage of NEO's development.

The sensor can provide fused orientation information for:

- heading estimation
- orientation monitoring
- turn-angle measurement

The BNO055 is **not currently installed in NEO's present physical configuration**.

The sensor and related software remain documented as part of the project's development history and may be reconsidered if heading information provides a useful performance advantage.

---

# Sensor Calibration

Sensor calibration is an important part of preparing NEO for autonomous operation.

The final calibration process can include:

- checking sensor orientation
- checking physical mounting
- confirming reliable distance readings
- identifying useful detection thresholds
- testing readings at different distances
- checking for interference from NEO's own chassis
- adjusting sensor positions where necessary

The camera also requires final calibration after its physical mounting position has been fixed.

---

# Sensor System Summary

NEO's sensing system combines:

- Raspberry Pi Camera 3 Wide
- VL53L5X Time-of-Flight sensing
- additional ToF ranging sensors
- front-centre distance sensing
- front-left distance sensing
- front-right distance sensing
- rear distance sensing
- TCA9548A I²C communication management

The camera provides visual understanding while the ToF sensors provide direct distance measurements.

Together, these systems provide the environmental information required by NEO's autonomous navigation architecture.

---

[← Back to Main README](../README.md)

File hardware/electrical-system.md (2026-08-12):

# NEO — Electrical & Power System

NEO's electrical system distributes power from a single **Bonka 11.1 V 2200 mAh LiPo battery** to the computing, sensing and motor-control systems.

Separate voltage-regulation paths are used for the Raspberry Pi and motor electronics to improve power stability and reduce interference between high-current motor loads and the main controller.

---

## Electrical Architecture

The main electrical architecture consists of:

**Bonka 11.1 V 2200 mAh LiPo Battery**  
↓  
**Power Distribution**  
↓  
**Voltage Regulation**  
↓  
**Computing + Sensors + Control Electronics + Actuators**

The two primary regulated power paths are:

### Raspberry Pi Power

**11.1 V LiPo Battery**  
↓  
**XL4015 5 V 5 A Buck Converter**  
↓  
**Raspberry Pi 5**

### Motor Electronics Power

**11.1 V LiPo Battery**  
↓  
**MP1584 3 A Buck Converter**  
↓  
**Motor Electronics**

<!-- UPLOAD HERE: Power architecture/block diagram -->

---

## Main Electrical Components

| Component | Electrical Function |
|---|---|
| Bonka 11.1 V 2200 mAh LiPo | Main power source |
| XL4015 5 V 5 A Buck Converter | Regulates power for Raspberry Pi 5 |
| MP1584 3 A Buck Converter | Regulates power for motor electronics |
| Raspberry Pi 5 | Main controller |
| TB6612FNG | Drive-motor control |
| PCA9685 | PWM control for steering |
| TCA9548A | I²C communication management |
| SG90 Micro Servo | Steering actuator |
| LEGO EV3 Medium Motor | Drive actuator |
| ToF Sensors | Distance sensing |
| Raspberry Pi Camera 3 Wide | Visual sensing |
| Push Button | Physical control input |

---

## Main Power Source

NEO uses a **Bonka 11.1 V 2200 mAh LiPo battery**.

The LiPo battery provides a high energy density while remaining compact enough to fit within NEO's chassis.

### Battery Specification

| Parameter | Value |
|---|---:|
| Nominal Voltage | 11.1 V |
| Capacity | 2200 mAh |
| Capacity in Ah | 2.2 Ah |
| Nominal Energy | ~24.4 Wh |

<!-- UPLOAD HERE: Photo of Bonka LiPo installed securely in NEO -->

---

## Battery Energy Calculation

Battery energy can be estimated using:

**Energy = Voltage × Capacity**

Therefore:

**Energy = 11.1 V × 2.2 Ah**

**Energy ≈ 24.42 Wh**

NEO therefore has approximately:

**24.4 Wh**

of nominal battery energy.

This value represents stored energy and should not be treated as an exact runtime measurement.

Actual runtime depends on factors including:

- Raspberry Pi processing load
- motor load
- motor speed
- steering activity
- sensor usage
- converter efficiency
- drivetrain resistance

---

## Why We Use Separate Power Regulation

The Raspberry Pi and propulsion electronics have different electrical requirements.

Motor operation can also introduce changes in current demand that may affect the stability of sensitive computing electronics.

NEO therefore uses separate buck converters for its major power systems.

This provides:

- dedicated voltage regulation
- improved Raspberry Pi supply stability
- reduced interaction between computing and motor loads
- easier electrical troubleshooting
- modular power distribution

---

## XL4015 — Raspberry Pi Power

The **XL4015 5 V 5 A buck converter** is used to regulate power for the Raspberry Pi 5.

The power path is:

**11.1 V Battery**  
↓  
**XL4015**  
↓  
**Regulated 5 V Supply**  
↓  
**Raspberry Pi 5**

The Raspberry Pi is one of NEO's most important electrical components because it controls the autonomous system.

Providing it with a dedicated regulated supply helps maintain reliable:

- camera operation
- sensor communication
- computer-vision processing
- autonomous decision-making

<!-- UPLOAD HERE: Photo of XL4015 installed on NEO -->

---

## MP1584 — Motor Electronics Power

The **MP1584 3 A DC-DC buck converter** is used for the motor-electronics power system.

The power path is:

**11.1 V Battery**  
↓  
**MP1584**  
↓  
**Motor Electronics**

Separating this power path from the Raspberry Pi supply helps prevent changes in motor load from directly affecting the main controller's regulated supply.

<!-- UPLOAD HERE: Photo of MP1584 installed on NEO -->

---

## Motor Driver — TB6612FNG

The LEGO EV3 Medium Motor cannot be powered directly from the Raspberry Pi.

NEO therefore uses a **TB6612FNG motor driver** between the controller and the drive motor.

The control path is:

**Raspberry Pi 5**  
↓  
**TB6612FNG**  
↓  
**LEGO EV3 Medium Motor**

The TB6612FNG allows the autonomous control system to manage motor operation while the motor receives power through the appropriate electrical path.

The driver provides control over:

- motor direction
- motor speed
- motor activation

[View NEO's drivetrain](../mobility/drivetrain.md)

---

## Steering Electronics

NEO's SG90 steering servo is controlled through the **PCA9685 PWM controller**.

The control path is:

**Raspberry Pi 5**  
↓  
**PCA9685**  
↓  
**SG90 Micro Servo**  
↓  
**Steering Mechanism**

The PCA9685 generates the PWM signal used to determine servo position.

This allows NEO to generate intermediate steering positions for autonomous corrections.

[View NEO's steering system](../mobility/steering.md)

---

## I²C Architecture

NEO uses I²C communication for several electronic devices.

The **TCA9548A 8-channel I²C multiplexer** allows multiple I²C devices to be organised across separate selectable channels.

The basic architecture is:

**Raspberry Pi 5**  
↓  
**I²C**  
↓  
**TCA9548A**  
↓  
**Connected I²C Devices**

This is particularly useful when multiple sensors use identical or conflicting I²C addresses.

[View NEO's sensor architecture](sensors.md)

---

## Camera Connection

The **Raspberry Pi Camera 3 Wide** connects directly to the Raspberry Pi through the CSI camera interface.

This means the camera does not require a separate USB connection.

The camera provides visual data directly to the Raspberry Pi for computer-vision processing.

**Pi Camera 3 Wide**  
↓  
**CSI Interface**  
↓  
**Raspberry Pi 5**

[View NEO's computer-vision system](../software/vision.md)

---

## Electrical Schematic

NEO's circuit diagram documents the electrical connections between the main computing, sensing, control and power components.

The schematic includes:

- Raspberry Pi 5
- PCA9685
- TCA9548A
- TB6612FNG
- ToF sensors
- SG90 Micro Servo
- LEGO EV3 Medium Motor
- XL4015
- MP1584
- LiPo battery
- signal connections
- power connections

<!-- UPLOAD HERE: Export FE2026_Schematic as a PNG and place it below -->

<p align="center">
  
</p>

<!-- UPLOAD HERE: Original FE2026_Schematic.pdf into the hardware folder -->

[Open Full Electrical Schematic](FE2026_Schematic.pdf)

---

## Battery Charging

NEO's LiPo battery is charged using an **iMAX B6AC Dual Power 80 W balance charger**.

A balance charger is used so that the cells within the LiPo battery can be charged appropriately.

Before testing, the battery condition is checked and the pack is securely installed within the chassis.

<!-- UPLOAD HERE: Photo of iMAX B6AC charger -->

---

## Physical Control

NEO includes a **push button** as a physical control input.

This provides a convenient way to interact with the robot during testing and competition operation without requiring direct access to the Raspberry Pi interface.

<!-- UPLOAD HERE: Close-up showing the push-button position on NEO -->

---

## Electrical Safety & Reliability

Several measures are used to improve the reliability of NEO's electrical system.

### Separate Power Regulation

The Raspberry Pi and motor electronics use separate buck converters.

### Secure Battery Mounting

The LiPo battery is secured within the chassis to prevent movement while NEO is driving.

### Secured Electronics

Electronic modules are mounted so that normal vehicle vibration does not cause excessive movement or accidental disconnection.

### Wiring Management

Wiring is routed away from:

- wheels
- gears
- axles
- steering linkage

This reduces the chance of wires interfering with moving mechanical components.

### Battery Checks

Battery voltage and condition are checked before operation to avoid excessive discharge.

### Balance Charging

The battery is charged using the iMAX B6AC balance charger.

---

## Electrical System Summary

NEO's electrical system is designed around a simple principle:

**One Main Battery → Separate Regulated Power Paths → Stable Computing and Motor Control**

The **11.1 V LiPo battery** provides the main energy source.

The **XL4015** regulates power for the Raspberry Pi, while the **MP1584** provides a separate regulated path for the motor electronics.

The Raspberry Pi then communicates with NEO's sensors and control electronics to connect perception, decision-making and physical movement.

---

[← Back to Main README](../README.md)

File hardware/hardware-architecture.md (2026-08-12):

# NEO — Hardware Architecture

NEO's hardware architecture connects its sensing, processing, steering, propulsion and power systems around a **Raspberry Pi 5**.

The Raspberry Pi acts as the central controller, receiving environmental information and generating commands for the vehicle's steering and drive systems.

---

## System Architecture

NEO's overall hardware flow can be represented as:

**Raspberry Pi Camera 3 Wide + ToF Distance Sensors**  
↓  
**Raspberry Pi 5**  
↓  
**Autonomous Processing & Decision Making**  
↓  
**Steering Control + Motor Control**  
↓  
**NEO's Movement**

The supporting electronics allow the Raspberry Pi to communicate with multiple sensors and safely control the vehicle's actuators.

<!-- UPLOAD HERE: Hardware architecture/block diagram -->

---

## Main Hardware Components

| Component | Function |
|---|---|
| Raspberry Pi 5 | Main processing and autonomous control |
| Raspberry Pi Camera 3 Wide | Computer vision |
| VL53L5X / ToF Sensors | Distance sensing |
| TCA9548A I²C Multiplexer | Manages multiple I²C devices |
| PCA9685 PWM Controller | Generates PWM signals for steering |
| SG90 Micro Servo | Controls front-wheel steering |
| TB6612FNG Motor Driver | Controls the drive motor |
| LEGO EV3 Medium Motor | Provides propulsion |
| LEGO Differential | Transfers drive to the rear wheels |
| Bonka 11.1 V 2200 mAh LiPo | Main power source |
| XL4015 5 V 5 A | Raspberry Pi power regulation |
| MP1584 3 A | Motor-electronics power regulation |
| Push Button | Physical control input |

---

## Raspberry Pi 5 — Central Controller

The **Raspberry Pi 5** acts as NEO's main controller.

It is responsible for bringing together the different autonomous systems of the vehicle.

Its tasks include:

- receiving camera information
- reading distance-sensor data
- processing computer vision
- running navigation algorithms
- calculating steering corrections
- generating motor-control commands
- coordinating autonomous behaviours

### Why We Chose the Raspberry Pi 5

The Raspberry Pi 5 was selected because it provides the processing capability required for real-time computer vision while supporting the hardware interfaces required by NEO.

| Requirement | Raspberry Pi 5 |
|---|---|
| Computer Vision | Supports OpenCV processing |
| Programming | Strong Python compatibility |
| Camera Interface | Native CSI support |
| Sensor Communication | Supports I²C and GPIO |
| Control | Can coordinate sensing and actuation |
| Expandability | Allows additional sensors and electronics |

<!-- UPLOAD HERE: Photo of Raspberry Pi 5 installed on NEO -->

---

## Camera Interface

NEO uses a **Raspberry Pi Camera 3 Wide** connected directly to the Raspberry Pi through the CSI interface.

The camera provides visual information for:

- obstacle detection
- obstacle colour recognition
- navigation
- parking

The wide field of view allows a larger portion of the competition environment to be visible within each frame.

The software is currently designed around:

| Parameter | Configuration |
|---|---:|
| Resolution | 640 × 480 |
| Frame Rate | Up to approximately 30 FPS |
| Processing | Python + OpenCV |

<!-- UPLOAD HERE: Photo of final Pi Camera 3 Wide installation -->

[View NEO's vision system](../software/vision.md)

---

## Distance Sensor Interface

NEO uses Time-of-Flight distance sensing around the vehicle.

The current sensor arrangement provides measurements from:

- front-left
- front-centre
- front-right
- rear

These measurements provide numerical information about surrounding clearance.

The distance-sensing system complements the camera by providing direct proximity measurements.

[View detailed sensor architecture](sensors.md)

---

## I²C Communication

Several of NEO's electronic devices communicate using **I²C**.

I²C allows multiple devices to exchange information with the Raspberry Pi using a shared communication bus.

NEO uses a **TCA9548A 8-channel I²C multiplexer** as part of this architecture.

The simplified communication path is:

**Raspberry Pi 5**  
↓  
**I²C Bus**  
↓  
**TCA9548A Multiplexer**  
↓  
**Connected I²C Devices**

The multiplexer allows different channels to be selected when communicating with connected devices.

This is particularly useful when multiple devices would otherwise create I²C address conflicts.

---

## TCA9548A I²C Multiplexer

The **TCA9548A** expands NEO's I²C architecture by providing eight selectable channels.

It is used to:

- organise communication with multiple sensors
- prevent address conflicts
- allow individual sensor channels to be selected
- make the sensing architecture easier to expand

<!-- UPLOAD HERE: Close-up photo of TCA9548A installed on NEO -->

---

## Steering Hardware

NEO's steering architecture consists of:

**Raspberry Pi 5**  
↓  
**PCA9685 PWM Controller**  
↓  
**SG90 Micro Servo**  
↓  
**Custom Servo Horn**  
↓  
**Front Steering Mechanism**

The Raspberry Pi determines the required steering correction.

The **PCA9685** then provides the PWM signal required to position the SG90 servo.

Using a dedicated PWM controller allows the servo-control signal to be handled separately from the Raspberry Pi's main processing workload.

[View NEO's steering system](../mobility/steering.md)

---

## PCA9685 PWM Controller

The **PCA9685** is a 16-channel PWM controller used as part of NEO's steering system.

Its primary role in NEO is to generate the PWM signal required by the SG90 Micro Servo.

The controller allows precise servo-position commands while reducing the need for software-generated PWM timing directly from the Raspberry Pi.

---

## Propulsion Hardware

NEO's propulsion-control architecture consists of:

**Raspberry Pi 5**  
↓  
**TB6612FNG Motor Driver**  
↓  
**LEGO EV3 Medium Motor**  
↓  
**LEGO Differential**  
↓  
**Rear Wheels**

The Raspberry Pi generates the required motor command, while the TB6612FNG provides the interface required to control the drive motor.

[View NEO's drivetrain](../mobility/drivetrain.md)

---

## TB6612FNG Motor Driver

The **TB6612FNG** acts as the interface between NEO's control electronics and the LEGO EV3 Medium Motor.

The Raspberry Pi cannot directly supply the electrical power required by the drive motor.

The motor driver therefore allows the low-power control system to control the higher-power propulsion system.

Its role includes:

- motor direction control
- motor speed control
- electrical separation between control signals and motor power

<!-- UPLOAD HERE: Close-up photo of TB6612FNG -->

---

## Physical Actuators

NEO has two primary actuators.

| Actuator | Function |
|---|---|
| LEGO EV3 Medium Motor | Propulsion |
| SG90 Micro Servo | Steering |

This keeps NEO's basic movement architecture simple:

**EV3 Motor = Speed / Propulsion**

**SG90 Servo = Direction / Steering**

The two systems are controlled independently by the autonomous software.

---

## Power Architecture

NEO's hardware is powered by a **Bonka 11.1 V 2200 mAh LiPo battery**.

Because different systems require regulated power, two buck converters are used.

### Raspberry Pi Power

**11.1 V LiPo**  
↓  
**XL4015 5 V 5 A Buck Converter**  
↓  
**Raspberry Pi 5**

### Motor Electronics Power

**11.1 V LiPo**  
↓  
**MP1584 3 A Buck Converter**  
↓  
**Motor Electronics**

Separating these power paths helps reduce the effect of motor-related voltage fluctuations on the Raspberry Pi.

<!-- UPLOAD HERE: Power architecture diagram -->

[View NEO's complete electrical system](electrical-system.md)

---

## Push Button

NEO includes a physical **push button** as part of the control architecture.

The button provides a direct physical input that can be used during testing and competition operation.

This allows interaction with the robot without requiring direct access to the Raspberry Pi interface each time.

<!-- UPLOAD HERE: Photo showing push-button position -->

---

## BNO055 Development

A **BNO055 IMU** was explored during NEO's development.

The sensor can provide fused orientation and heading information for applications such as:

- heading estimation
- turn-angle measurement
- orientation correction

The BNO055 is **not currently installed in NEO's present physical configuration**.

Its previous inclusion remains documented because it formed part of the development and evaluation of NEO's sensing architecture.

---

## Hardware Integration

NEO's hardware was designed as a modular system.

Rather than permanently integrating every electronic function into a single board, the current architecture uses separate modules.

This allows individual components to be:

- replaced
- repositioned
- tested independently
- upgraded
- removed if no longer required

This modularity is particularly useful during development, when sensor positions and control hardware may need to change.

<!-- UPLOAD HERE: Clear top-view photo of NEO with electronics exposed -->

---

## Hardware Architecture Summary

NEO's hardware architecture can be divided into five layers:

### 1. Sensing
**Pi Camera 3 Wide + ToF Sensors**

↓

### 2. Processing
**Raspberry Pi 5**

↓

### 3. Communication & Control
**TCA9548A + PCA9685 + TB6612FNG**

↓

### 4. Actuation
**SG90 Servo + LEGO EV3 Medium Motor**

↓

### 5. Movement
**Front Steering + Rear-Wheel Drive**

The complete system connects environmental sensing directly to autonomous physical movement while maintaining a modular architecture that can continue to evolve during development.

---

[← Back to Main README](../README.md)

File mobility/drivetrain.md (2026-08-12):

# NEO — Drivetrain

NEO uses a compact **rear-wheel-drive drivetrain** powered by a LEGO EV3 Medium Motor and a LEGO differential.

The drivetrain was designed to provide reliable propulsion while keeping the drive system mechanically separate from the front steering system.

---

## Drivetrain Architecture

NEO's drivetrain follows the basic power path:

**LEGO EV3 Medium Motor**  
↓  
**LEGO Gear System**  
↓  
**LEGO Differential**  
↓  
**Rear Axle**  
↓  
**Rear Wheels**

The rear wheels provide propulsion, while the front wheels are responsible for steering.

<!-- UPLOAD HERE: Clear top or bottom photograph showing the complete drivetrain -->

---

## Rear-Wheel Drive

NEO uses a **rear-wheel-drive configuration**.

In this arrangement:

- the rear axle provides propulsion
- the front wheels provide steering
- the propulsion and steering mechanisms operate independently

Separating these functions simplifies the mechanical architecture and allows changes to the steering system without redesigning the complete drivetrain.

---

## Drive Motor

NEO is powered by a **LEGO EV3 Medium Motor**.

The EV3 Medium Motor was selected because its compact dimensions allow it to fit within NEO's 195 mm × 111 mm chassis while integrating directly with LEGO axles, gears and drivetrain components.

Using a LEGO-based drive motor also allows the drivetrain to remain modular, making mechanical adjustments easier during development.

<!-- UPLOAD HERE: Close-up photo of the LEGO EV3 Medium Motor installed in NEO -->

---

## LEGO Differential

A LEGO differential is installed on NEO's rear driven axle.

When a vehicle turns, the outside wheel must travel a greater distance than the inside wheel. If both driven wheels were mechanically forced to rotate at exactly the same speed, one wheel would need to slip during the turn.

The differential allows the rear wheels to rotate at different speeds while still receiving power from the drive motor.

### Advantages

The differential helps:

- reduce wheel slip during turns
- improve cornering
- reduce mechanical stress
- provide smoother drivetrain movement

<!-- UPLOAD HERE: Close-up photo of NEO's LEGO differential -->

---

## Rear Axle

The differential transfers power to the **rear axle**, which drives NEO's rear wheels.

The rear track width is:

**85 mm**

The drivetrain components are positioned within the chassis to maintain a compact overall vehicle width while leaving sufficient space for the battery and electronics.

---

## Wheels

NEO uses wheels with an approximate radius of:

**30 mm**

Therefore:

**Wheel Diameter = 60 mm**

The theoretical wheel circumference is:

**C = 2πr**

**C = 2π(0.03)**

**C ≈ 0.1885 m**

One complete wheel rotation therefore corresponds to approximately **0.1885 m of theoretical travel**, assuming no wheel slip.

[View full wheel and speed calculations](calculations.md)

---

## Motor Control

The LEGO EV3 Medium Motor is controlled using the **TB6612FNG motor driver**.

The control path is:

**Raspberry Pi 5**  
↓  
**TB6612FNG Motor Driver**  
↓  
**LEGO EV3 Medium Motor**  
↓  
**Differential**  
↓  
**Rear Wheels**

The motor driver allows the Raspberry Pi's autonomous control system to manage propulsion without directly supplying the electrical power required by the motor.

[View NEO's electrical system](../hardware/electrical-system.md)

---

## Drivetrain Geometry

| Parameter | NEO |
|---|---:|
| Drive Type | Rear-wheel drive |
| Drive Motor | LEGO EV3 Medium Motor |
| Differential | LEGO Differential |
| Wheel Radius | 30 mm |
| Wheel Diameter | 60 mm |
| Rear Track Width | 85 mm |
| Wheelbase | 150 mm |

<!-- UPLOAD HERE: Labelled image showing motor, differential, rear axle and rear wheels -->

---

## Recorded Performance

During current testing, NEO has completed one lap of the mat in approximately:

**8.7 seconds**

This is an observed performance result and is kept separate from the theoretical drivetrain calculations.

The theoretical calculations for wheel circumference, linear speed and wheel RPM are documented separately.

[View NEO's mobility calculations](calculations.md)

---

## Drivetrain Design Summary

NEO's drivetrain combines:

- LEGO EV3 Medium Motor propulsion
- rear-wheel drive
- LEGO differential
- 85 mm rear track width
- 60 mm diameter wheels
- modular LEGO drivetrain components

The drivetrain provides a compact propulsion system while allowing the front steering mechanism to operate independently.

---

[← Back to Main README](../README.md)

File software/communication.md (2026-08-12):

# NEO — Communication System

NEO's electronic systems must exchange information reliably so that sensor data, processing and physical movement can operate together.

The **Raspberry Pi 5** acts as NEO's main processing computer, while the supporting electronics handle sensing, steering and motor control.

---

## Communication Architecture

NEO's communication structure can be represented as:

```text
                  Pi Camera 3 Wide
                         │
                        CSI
                         │
                         ↓
ToF Sensors ─────→ Raspberry Pi 5
                         │
                         │
              Control / Processing
                         │
             ┌───────────┴───────────┐
             ↓                       ↓
         PCA9685                 TB6612FNG
             ↓                       ↓
        SG90 Servo            EV3 Medium Motor
```

<!-- UPLOAD HERE: Final communication architecture diagram -->

---

# Raspberry Pi 5

The Raspberry Pi 5 is the main processing platform used by NEO.

It is responsible for coordinating information from the robot's sensing systems and generating the control decisions required for autonomous movement.

The Raspberry Pi handles:

- computer vision
- sensor information
- autonomous navigation logic
- steering commands
- propulsion commands

---

# Camera Communication

The **Raspberry Pi Camera 3 Wide** connects directly to the Raspberry Pi through the camera interface.

```text
Pi Camera 3 Wide
       ↓
      CSI
       ↓
Raspberry Pi 5
```

This provides the Raspberry Pi with image frames for OpenCV-based visual processing.

[View NEO's computer-vision system](vision.md)

---

# I2C Communication

Several of NEO's electronic components use the **I2C communication protocol**.

I2C allows multiple compatible devices to communicate using a shared communication bus.

NEO includes a **TCA9548A 8-channel I2C multiplexer**, which helps manage multiple I2C devices within the system.

```text
Raspberry Pi 5
      ↓
     I2C
      ↓
   TCA9548A
   Multiplexer
      ↓
 Multiple I2C Devices
```

This is particularly useful when several sensors need to communicate through the same controller.

---

# Time-of-Flight Sensor Communication

NEO uses **VL53L5X Time-of-Flight laser-ranging sensors** for distance measurements.

The sensors provide distance information that can be used by the autonomous-navigation software.

A simplified communication path is:

```text
VL53L5X ToF Sensors
        ↓
      I2C
        ↓
     TCA9548A
        ↓
  Raspberry Pi 5
```

The Raspberry Pi can then combine these distance readings with information obtained from the camera.

[View NEO's sensor system](../hardware/sensors.md)

---

# PCA9685 Communication

NEO uses a **PCA9685 16-channel PWM controller** as part of the steering-control system.

The Raspberry Pi communicates with the PCA9685, which generates the PWM signal required by the SG90 steering servo.

```text
Raspberry Pi 5
      ↓
     I2C
      ↓
    PCA9685
      ↓
     PWM
      ↓
 SG90 Micro Servo
```

This separates the generation of the servo-control signal from the main processing performed by the Raspberry Pi.

---

# Steering Communication

The complete steering-command path can be represented as:

```text
Sensor + Camera Information
           ↓
     Raspberry Pi 5
           ↓
    Steering Decision
           ↓
        PCA9685
           ↓
      PWM Signal
           ↓
     SG90 Micro Servo
           ↓
     Front Steering
```

[View NEO's steering system](../mobility/steering.md)

---

# Motor Communication

NEO's propulsion system uses a **TB6612FNG motor driver** and a **LEGO EV3 Medium Motor**.

The motor driver acts as the interface between the control electronics and the propulsion motor.

```text
Raspberry Pi 5
      ↓
 Motor Command
      ↓
  TB6612FNG
      ↓
EV3 Medium Motor
      ↓
 Differential
      ↓
 Rear Wheels
```

The motor driver allows the low-power control system to command the motor without powering it directly from the Raspberry Pi.

[View NEO's drivetrain](../mobility/drivetrain.md)

---

# Power and Communication Separation

NEO uses separate voltage regulation for different parts of the electronic system.

### Motor Power

An **MP1584 DC-DC 3A buck converter** is used in the motor-power system.

### Raspberry Pi Power

An **XL4015 5V 5A converter** is used to provide suitable power for the Raspberry Pi.

The use of dedicated power-conversion hardware helps ensure that the computing and motor systems receive the voltages required for their respective operation.

```text
             Bonka LiPo Battery
                    ↓
          Power Distribution
             ↙             ↘
        MP1584            XL4015
           ↓                 ↓
     Motor System      Raspberry Pi 5
```

[View NEO's electrical system](../hardware/electrical.md)

---

# Communication During Autonomous Operation

During autonomous operation, communication occurs continuously.

A simplified cycle is:

```text
1. Sensors collect information
            ↓
2. Camera captures visual data
            ↓
3. Raspberry Pi processes inputs
            ↓
4. Navigation decision is calculated
            ↓
5. Steering and motor commands are generated
            ↓
6. NEO moves
            ↓
7. New information is collected
            ↓
          REPEAT
```

This allows NEO to continuously update its behaviour as the environment changes.

---

# Communication Reliability

Reliable communication is important because delays or incorrect data can affect autonomous driving.

During testing, Team Astra checks:

- whether sensors are detected correctly
- whether sensor readings update consistently
- whether the camera provides usable frames
- whether steering commands reach the servo correctly
- whether motor commands produce the expected movement
- whether components remain responsive during a complete run

<!-- UPLOAD HERE: Photo of electronics/wiring during testing -->

---

# Communication Testing

Individual communication systems can be tested before the entire autonomous program is run.

```text
Test Camera
     ↓
Test ToF Sensors
     ↓
Test PCA9685 + Servo
     ↓
Test Motor Driver + Motor
     ↓
Combine Systems
     ↓
Autonomous Test
```

Testing components individually makes communication problems easier to identify.

---

# Communication Summary

NEO uses several communication methods to connect its electronic systems:

| Connection | Purpose |
|---|---|
| CSI | Pi Camera 3 Wide → Raspberry Pi 5 |
| I2C | Communication with compatible control and sensing electronics |
| TCA9548A | Management of multiple I2C devices |
| PCA9685 / PWM | Steering-servo control |
| TB6612FNG | Interface between control system and drive motor |

Together, these connections allow information to move through the robot from **sensing → processing → decision-making → physical movement**.

---

[← Back to Main README](../README.md)

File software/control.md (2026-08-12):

# NEO — Autonomous Control System

NEO's autonomous control system connects its **camera, distance sensors, steering system and drivetrain** through the Raspberry Pi 5.

The objective of the control system is to continuously gather information about the environment, process that information and convert it into steering and propulsion commands.

---

## Control Architecture

NEO's autonomous-control loop can be represented as:

```text
Camera + ToF Sensors
        ↓
   Raspberry Pi 5
        ↓
 Environment Analysis
        ↓
  Driving Decision
        ↓
Steering + Motor Control
        ↓
     Movement
        ↓
 New Sensor Readings
        ↺
```

This process repeats continuously while NEO is operating autonomously.

<!-- UPLOAD HERE: Autonomous control block diagram -->

---

# Main Controller

The **Raspberry Pi 5** acts as NEO's central processing unit.

It coordinates:

- camera processing
- distance-sensor readings
- obstacle detection
- navigation decisions
- steering commands
- motor commands

This allows sensing, decision-making and movement to operate as one integrated system.

---

# Software Architecture

NEO's software can be understood as several connected layers:

```text
PERCEPTION
Camera + ToF Sensors
        ↓
PROCESSING
Computer Vision + Distance Analysis
        ↓
DECISION MAKING
Navigation Logic
        ↓
CONTROL
Steering + Motor Commands
        ↓
ACTUATION
SG90 Servo + EV3 Medium Motor
```

Each layer converts information into a form that can be used by the next stage.

---

# Main Control Loop

At a high level, NEO follows this repeated process:

```text
START
  ↓
Initialise Hardware
  ↓
Read Sensors
  ↓
Capture Camera Frame
  ↓
Process Environment
  ↓
Determine Required Movement
  ↓
Calculate Steering Command
  ↓
Calculate Motor Command
  ↓
Send Commands
  ↓
Repeat
```

This continuous loop allows NEO to react as its position and surroundings change.

---

# Perception

The first stage of autonomous control is understanding the environment.

NEO uses two main sources of information:

### Camera

The **Raspberry Pi Camera 3 Wide** provides visual information that can be processed using OpenCV.

It can contribute information about:

- obstacle colour
- obstacle position
- visual navigation features

### Distance Sensors

The ToF sensors provide direct measurements of surrounding clearance.

NEO currently uses sensing positions covering:

- front-left
- front-centre
- front-right
- rear

[View NEO's sensor system](../hardware/sensors.md)

[View NEO's computer-vision system](vision.md)

---

# Decision Making

Once sensor and camera information has been processed, the software determines how NEO should respond.

A simplified decision process is:

```text
Read Environment
       ↓
Is a Correction Required?
       ↓
Determine Direction
       ↓
Determine Steering Amount
       ↓
Determine Motor Command
       ↓
Execute Movement
```

The exact response depends on the current autonomous behaviour and the information available from the sensing system.

---

# Steering Control

NEO uses an **SG90 Micro Servo** for steering.

The Raspberry Pi determines the required steering position and the **PCA9685 PWM controller** generates the PWM signal used to control the servo.

```text
Raspberry Pi 5
      ↓
Steering Command
      ↓
PCA9685
      ↓
PWM Signal
      ↓
SG90 Servo
      ↓
Front Steering
```

The steering system supports:

- straight driving
- left corrections
- right corrections
- larger turning movements

NEO's measured maximum steering is approximately:

- **Left: 60°**
- **Right: slightly above 45°**

These values are approximate physical observations rather than precision measurements.

[View NEO's steering system](../mobility/steering.md)

---

# Propulsion Control

NEO uses a **LEGO EV3 Medium Motor** for propulsion.

The vehicle uses a rear-wheel-drive layout.

```text
Raspberry Pi 5
      ↓
Motor Command
      ↓
TB6612FNG
      ↓
EV3 Medium Motor
      ↓
LEGO Differential
      ↓
Rear Wheels
```

The differential allows the two driven rear wheels to rotate at different speeds while NEO turns.

[View NEO's drivetrain](../mobility/drivetrain.md)

---

# Camera-Based Steering

Visual information can contribute to steering decisions.

After an obstacle or relevant visual feature is detected, the software can estimate its horizontal position in the camera frame.

For a **640 × 480** frame:

```text
Image Centre ≈ 320 px
```

A simplified error calculation can be represented as:

```text
Error = Desired Position - Detected Position
```

The sign and magnitude of this error can then contribute to the required steering correction.

```text
Detected Position
       ↓
Calculate Error
       ↓
Determine Correction
       ↓
Steering Command
```

This allows steering decisions to respond to where an object appears within the camera view.

---

# Distance-Based Control

The ToF sensors provide additional information about the available space around NEO.

A simplified distance-control process is:

```text
Read ToF Sensors
       ↓
Compare Distances
       ↓
Determine Available Space
       ↓
Select Appropriate Movement
```

This information can support:

- obstacle clearance
- wall-distance monitoring
- collision prevention
- parking
- reverse movement

The ToF system therefore complements the visual information from the camera.

---

# Sensor Fusion

Camera and ToF information provide different types of data.

```text
Camera
   ↓
Colour + Visual Position
   ↓
           Raspberry Pi 5
   ↑
Distance + Clearance
   ↑
ToF Sensors
```

The control system can use both sources when determining the required response.

This reduces reliance on a single sensing method.

---

# Open Challenge Control

For the Open Challenge, NEO must autonomously navigate the competition field.

The control structure can be represented as:

```text
Start
  ↓
Detect Environment
  ↓
Maintain Course
  ↓
Detect Upcoming Turn
  ↓
Adjust Steering
  ↓
Complete Turn
  ↓
Continue Navigation
  ↓
Complete Required Laps
```

<!-- UPLOAD HERE: Open Challenge control-flow diagram -->

<!-- UPLOAD HERE: Open Challenge performance video/GIF -->

---

# Obstacle Challenge Control

For the Obstacle Challenge, visual obstacle information becomes an important part of the navigation process.

A simplified structure is:

```text
Capture Camera Frame
        ↓
Detect Relevant Obstacle
        ↓
Identify Colour
        ↓
Determine Position
        ↓
Check Distance Information
        ↓
Select Navigation Response
        ↓
Steer Around Obstacle
        ↓
Continue Course
```

The exact steering response depends on the detected environment and NEO's position relative to the obstacle.

<!-- UPLOAD HERE: Obstacle Challenge control-flow diagram -->

<!-- UPLOAD HERE: Obstacle Challenge performance video/GIF -->

---

# Physical Start Control

NEO includes a **push button** as a physical control input.

This allows the robot to receive a direct physical command during testing and competition preparation without requiring repeated interaction with the Raspberry Pi interface.

The button can form part of the start procedure:

```text
System Ready
     ↓
Button Input
     ↓
Begin Autonomous Routine
```

---

# Performance

During testing, NEO has completed approximately one round of the mat in:

**8.7 seconds**

This is an observed performance value rather than a calculated theoretical maximum speed.

The final performance can vary depending on:

- motor command
- battery condition
- steering corrections
- course configuration
- sensor behaviour
- obstacle placement

---

# Control System Testing

The control software is tested progressively rather than only as a complete system.

Individual testing can include:

### Sensor Testing

Confirm that distance measurements are being received correctly.

### Camera Testing

Confirm that the required visual features are detected reliably.

### Steering Testing

Confirm that requested steering positions produce the expected wheel movement.

### Motor Testing

Confirm that propulsion responds correctly to control commands.

### Integrated Testing

Combine sensing, decision-making and movement on the competition field.

This makes faults easier to isolate before full autonomous testing.

<!-- UPLOAD HERE: Photo of NEO during autonomous testing -->

---

# Fail-Safe Behaviour

Reliable autonomous operation requires NEO to avoid acting on clearly unusable information where possible.

During development, the software can account for conditions such as:

- missing sensor readings
- invalid distance measurements
- no relevant camera detection
- temporary loss of a visual target

Where useful information is unavailable, the control logic should avoid making unnecessarily aggressive corrections based on unreliable input.

---

# Control Development

NEO's control system is continuously refined through testing.

The development cycle follows:

```text
Run NEO
   ↓
Observe Behaviour
   ↓
Identify Problem
   ↓
Adjust Software / Hardware
   ↓
Test Again
```

This allows the control parameters to evolve alongside changes to sensor placement, steering geometry and the camera system.

---

# Autonomous Control Summary

NEO's autonomous-control system combines:

- Raspberry Pi 5
- Raspberry Pi Camera 3 Wide
- OpenCV-based visual processing
- Time-of-Flight distance sensing
- PCA9685 steering control
- SG90 Micro Servo
- TB6612FNG motor control
- LEGO EV3 Medium Motor
- rear-wheel-drive differential system

Together, these systems create the central autonomous loop:

```text
SENSE → PROCESS → DECIDE → ACT → REPEAT
```

This allows NEO to convert information from its environment into physical steering and propulsion commands without manual control.

---

[← Back to Main README](../README.md)

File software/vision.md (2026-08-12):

# NEO — Computer Vision System

NEO uses a **Raspberry Pi Camera 3 Wide** together with the **Raspberry Pi 5** for visual perception.

The camera provides information about the competition field, while Python and OpenCV process the captured frames so that NEO can identify relevant visual features and use them during autonomous navigation.

---

## Vision Architecture

NEO's computer-vision pipeline can be represented as:

```text
Raspberry Pi Camera 3 Wide
            ↓
       Camera Frame
            ↓
       Raspberry Pi 5
            ↓
      OpenCV Processing
            ↓
   Visual Feature Detection
            ↓
 Position / Colour Information
            ↓
   Autonomous Decision Making
            ↓
 Steering + Motor Commands
```

<!-- UPLOAD HERE: Computer vision block diagram -->

---

# Camera

NEO uses the **Raspberry Pi Camera 3 Wide** as its primary visual sensor.

The wide-angle camera was selected to provide a larger field of view in front of the robot, allowing more of the competition environment to be visible within each frame.

### Current Camera Configuration

| Parameter | Configuration |
|---|---|
| Camera | Raspberry Pi Camera 3 Wide |
| Main Processor | Raspberry Pi 5 |
| Resolution | 640 × 480 |
| Frame Rate | Up to approximately 30 FPS |
| Processing Language | Python |
| Vision Library | OpenCV |
| Interface | CSI |

<!-- UPLOAD HERE: Photo of Pi Camera 3 Wide -->

<!-- UPLOAD LATER: Final photo of camera mounted on NEO -->

---

# Camera Mount

The Pi Camera 3 Wide is supported using custom 3D-printed components developed specifically for NEO.

The camera assembly includes:

- Pi Camera 3 Mount
- Camera Stand V2
- Camera Stand V3

The camera-support system went through multiple versions so that its position could be refined independently from the rest of the robot.

[View NEO's 3D-printed camera components](../3d-models/README.md)

The final camera height and mounting angle will be documented after the competition configuration is fixed.

---

# Image Acquisition

During operation, frames from the Pi Camera are captured and passed to the Raspberry Pi 5.

Each frame becomes an input to NEO's computer-vision pipeline.

```text
Camera
   ↓
Capture Frame
   ↓
Prepare Image
   ↓
Process with OpenCV
   ↓
Extract Useful Information
```

The goal is not simply to record video. The captured images are converted into information that NEO's autonomous-control software can use.

---

# Image Processing

OpenCV is used to process camera frames.

Depending on the autonomous behaviour being executed, the vision pipeline can perform operations such as:

- frame acquisition
- colour-space conversion
- image masking
- contour detection
- object localisation
- position estimation
- filtering of irrelevant detections

This reduces the raw camera image into information useful for navigation.

<!-- UPLOAD HERE: Screenshot showing an example raw camera frame -->

<!-- UPLOAD HERE: Screenshot showing the same frame after OpenCV processing -->

---

# Colour Detection

Colour detection is used to distinguish relevant visual features within the competition environment.

A simplified colour-processing pipeline is:

```text
Camera Frame
      ↓
Colour-Space Conversion
      ↓
Apply Colour Threshold
      ↓
Generate Mask
      ↓
Find Relevant Regions
      ↓
Determine Position
```

The exact threshold values can be adjusted during testing to account for changes in:

- lighting
- camera position
- exposure
- competition-field conditions

This makes calibration an important part of the final vision setup.

---

# Red and Green Recognition

NEO's vision system is designed to distinguish relevant **red and green obstacles**.

After colour filtering, the software can determine where a detected obstacle appears within the camera frame.

For example:

```text
Detected Object
      ↓
Determine Colour
      ↓
Determine Position
      ↓
Send Information to Navigation Logic
```

The navigation system can then use this information when deciding the required steering response.

<!-- UPLOAD HERE: Screenshot of red obstacle detection -->

<!-- UPLOAD HERE: Screenshot of green obstacle detection -->

---

# Object Position

Once a relevant region has been detected, its position within the frame can be estimated.

A common representation is the centre of the detected region:

```text
Object Centre = (x, y)
```

The horizontal position is particularly useful for steering decisions.

For a frame width of **640 pixels**, the approximate image centre is:

```text
x = 320
```

The difference between the desired position and detected position can then be used as an error value.

```text
Error = Desired Position - Detected Position
```

This error can contribute to NEO's steering correction.

---

# Contour Detection

After creating a colour mask, OpenCV can identify connected regions or contours.

Contours allow the software to estimate properties such as:

- object position
- bounding region
- centre point
- apparent size

Small or irrelevant detections can be filtered so that the navigation system focuses on useful visual information.

<!-- UPLOAD HERE: Screenshot showing detected contour/bounding box -->

---

# Vision and Steering

The information generated by the camera is passed to NEO's autonomous-control system.

A simplified control sequence is:

```text
Camera
   ↓
Obstacle Detection
   ↓
Obstacle Position
   ↓
Calculate Error
   ↓
Calculate Steering Correction
   ↓
SG90 Servo
```

The size and direction of the detected error can therefore influence the steering command.

[View NEO's steering system](../mobility/steering.md)

---

# Vision and Distance Sensors

NEO does not rely only on camera information.

The camera works alongside the Time-of-Flight distance sensors.

The two sensing systems provide complementary information:

| Camera | ToF Sensors |
|---|---|
| Identifies visual features | Measures distance |
| Distinguishes colour | Measures proximity |
| Estimates object position in image | Provides directional clearance |
| Covers a wide visual region | Measures specific regions around NEO |

A simplified sensor-fusion concept is:

```text
        Camera
          ↓
 Visual Information
          ↓
     Raspberry Pi 5
          ↑
 Distance Information
          ↑
      ToF Sensors
```

The Raspberry Pi can use both sources when determining the appropriate autonomous behaviour.

[View NEO's sensor system](../hardware/sensors.md)

---

# Vision Calibration

Computer vision can be affected by environmental conditions.

Before competition operation, the vision system can be calibrated for:

- camera position
- camera angle
- colour thresholds
- lighting conditions
- useful detection area
- minimum relevant contour size
- obstacle visibility

The final calibration values depend on the completed physical camera installation and testing conditions.

---

# Why Raspberry Pi 5?

Computer vision requires significantly more processing than simple sensor readings.

The Raspberry Pi 5 was selected as NEO's main controller because it can run the Python and OpenCV processing required by the vision system while also coordinating the rest of the autonomous vehicle.

This allows the main sequence to remain:

```text
SEE
 ↓
PROCESS
 ↓
DECIDE
 ↓
MOVE
```

---

# Development & Testing

The computer-vision system is tested using camera frames containing the visual features NEO is expected to encounter.

During development, Team Astra can evaluate:

- whether the required colours are detected
- whether false detections occur
- whether object positions are calculated correctly
- whether detection remains stable as NEO moves
- whether steering responds appropriately to visual information

The camera mounting position can then be adjusted alongside the software parameters.

<!-- UPLOAD HERE: Photo/screenshot of Team Astra testing the vision system -->

---

# Example Vision Output

Once the final vision system is tested, this section will contain examples of NEO's processed camera output.

<!-- UPLOAD HERE: RAW FRAME -->

<!-- UPLOAD HERE: COLOUR MASK -->

<!-- UPLOAD HERE: FINAL DETECTION WITH CONTOUR / CENTRE POINT -->

These images will demonstrate the progression from the original camera input to the information used by the autonomous navigation software.

---

# Vision System Summary

NEO's computer-vision system combines:

- Raspberry Pi Camera 3 Wide
- Raspberry Pi 5
- Python
- OpenCV
- colour processing
- contour detection
- obstacle localisation
- visual steering information
- ToF distance sensing

The camera allows NEO to visually interpret the competition environment, while the Raspberry Pi converts that visual information into data that can contribute to autonomous navigation decisions.

---

[← Back to Main README](../README.md)

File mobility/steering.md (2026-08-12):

# NEO — Steering System

NEO uses **front-wheel steering** controlled by an **SG90 Micro Servo**.

The steering system is mechanically independent from the rear-wheel drivetrain, allowing NEO to control its direction while the rear axle provides propulsion.

---

## Steering Architecture

NEO's steering-control path is:

**Raspberry Pi 5**  
↓  
**PCA9685 PWM Controller**  
↓  
**SG90 Micro Servo**  
↓  
**Servo Horn**  
↓  
**Steering Mechanism**  
↓  
**Front Wheels**

This converts steering decisions made by the autonomous software into physical movement of the front wheels.

<!-- UPLOAD HERE: Clear photo of NEO's complete front steering system -->

---

## SG90 Micro Servo

An **SG90 Micro Servo** controls NEO's steering.

The servo was selected because it is:

- compact
- lightweight
- easy to integrate into the chassis
- capable of controlled angular positioning
- suitable for NEO's small steering mechanism

Unlike a standard DC motor, a servo can be commanded to specific positions. This allows NEO to make intermediate steering corrections rather than relying only on full-left, straight and full-right movement.

<!-- UPLOAD HERE: Close-up photo of the SG90 installed in NEO -->

---

## Custom Servo Mounting

Two custom 3D-printed components are used in NEO's steering assembly:

### Servo Stand

The **Servo Stand** securely positions the SG90 Micro Servo within the vehicle.

A dedicated mount reduces unwanted servo movement and allows the steering system to remain aligned with the chassis.

### 13 mm Servo Horn

The custom **13 mm Servo Horn** connects the servo output to the steering mechanism.

Its purpose is to transfer the rotational movement of the servo into movement of the steering linkage.

| Servo Stand | 13 mm Servo Horn |
|---|---|
| Servo Stand | 13 mm Servo Horn |

[View the 3D-printable steering components](../3d-models/README.md)

---

## Front-Wheel Steering

NEO's rear wheels are responsible for propulsion, while its front wheels determine direction.

When the servo rotates:

1. The servo horn moves.
2. The steering linkage transfers this movement.
3. The front wheels change angle.
4. NEO changes direction.

This separation between propulsion and steering keeps the mechanical system modular and allows each system to be adjusted independently.

<!-- UPLOAD HERE: Top-view photo showing the front wheels and steering linkage -->

---

## Steering Range

The current observed maximum steering range is approximately:

| Direction | Approximate Maximum |
|---|---:|
| Left | ~60° |
| Right | Slightly above 45° |

These values were visually estimated during development and are **not final measured values**.

The exact left and right steering angles will be updated after final calibration.

<!-- OPTIONAL UPLOAD HERE: Photo showing maximum left steering -->

<!-- OPTIONAL UPLOAD HERE: Photo showing maximum right steering -->

---

## Steering Control

The autonomous software calculates the steering correction required from the current sensor and camera information.

The command is then sent through the PCA9685 to the SG90 servo.

**Environmental Input**  
↓  
**Navigation Algorithm**  
↓  
**Desired Steering Correction**  
↓  
**PCA9685**  
↓  
**SG90 Servo**  
↓  
**Front-Wheel Angle**

The use of PWM control allows the servo to move to intermediate positions for smoother autonomous corrections.

[View NEO's autonomous control system](../software/control.md)

---

## Proportional Steering

NEO can use proportional steering so that the size of the steering correction depends on the size of the detected error.

The basic relationship is:

**Error = Desired Condition − Measured Condition**

The correction can then be represented as:

**Steering Correction = Kp × Error**

where **Kp** is the proportional gain.

This means:

- small error → small steering correction
- large error → larger steering correction

This is useful for autonomous navigation because NEO does not always need to make a maximum steering movement.

---

## Steering Limits

The calculated steering output is constrained before being sent to the servo.

Software limits help prevent normal autonomous commands from unnecessarily forcing the steering mechanism beyond its usable range.

This protects the steering assembly and provides more predictable control.

---

## Steering Geometry

NEO's steering geometry is influenced by its overall dimensions.

| Parameter | Measurement |
|---|---:|
| Wheelbase | 150 mm |
| Front Track Width | 85 mm |
| Approximate Maximum Left Steering | ~60° |
| Approximate Maximum Right Steering | >45° |

The relationship between wheelbase, track width and steering angle affects the turning behaviour of the vehicle.

Once the final steering angles are precisely measured, the minimum theoretical turning radius can also be calculated more accurately.

---

## Steering Calibration

Before autonomous operation, the steering system should be calibrated to identify:

- servo centre position
- straight-wheel position
- usable maximum left position
- usable maximum right position

The mechanical centre of the steering system should correspond as closely as possible to the software's straight-ahead command.

Final calibration will also allow the approximate steering-angle values currently documented to be replaced with measured values.

---

## Steering Development

The steering system was designed to remain modular.

Using a dedicated **Servo Stand** and **13 mm Servo Horn** means these components can be redesigned and reprinted independently if the steering geometry needs to be changed.

This allows Team Astra to refine the steering system without rebuilding NEO's complete chassis.

<!-- UPLOAD HERE: CAD or photo showing the servo mounting and steering mechanism -->

---

## Steering System Summary

NEO's steering system combines:

- front-wheel steering
- SG90 Micro Servo
- PCA9685 PWM control
- custom Servo Stand
- custom 13 mm Servo Horn
- proportional steering capability
- configurable software steering limits

Together, the mechanical and software systems allow autonomous navigation commands to be converted into controlled movement of NEO's front wheels.

---

[← Back to Main README](../README.md)

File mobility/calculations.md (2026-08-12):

# NEO — Mobility Calculations

This page documents the main calculations used to understand NEO's wheel movement, theoretical speed and required wheel RPM.

These calculations are theoretical and are kept separate from experimentally recorded performance.

---

## Known Values

| Parameter | Value |
|---|---:|
| Wheel Radius | 0.03 m |
| Wheel Diameter | 0.06 m |
| Estimated Distance for 3 Laps | 26.4 m |
| Recorded Lap Time | Approximately 8.7 s |

---

## 1. Wheel Circumference

NEO uses wheels with a radius of approximately:

**r = 0.03 m**

Wheel circumference is calculated using:

**C = 2πr**

Therefore:

**C = 2 × π × 0.03**

**C ≈ 0.1885 m**

This means that one complete wheel rotation theoretically moves NEO approximately:

**0.1885 m**

This assumes no wheel slip.

---

## 2. Estimated Track Distance

For our mobility calculations, the approximate distance travelled over three laps was taken as:

**Distance ≈ 26.4 m**

This value is used to estimate the linear speed and wheel RPM required for different target completion times.

<!-- UPLOAD HERE: Image of handwritten track-distance calculation -->

---

## 3. Theoretical Speed at 100%

For the theoretical calculation, a three-lap time of approximately:

**27 seconds**

was used.

Linear speed is calculated using:

**Speed = Distance ÷ Time**

Therefore:

**Speed = 26.4 ÷ 27**

**Speed ≈ 0.978 m/s**

NEO would therefore require an average theoretical linear speed of approximately:

**0.98 m/s**

---

## 4. Theoretical Wheel RPM at 100%

The wheel circumference is approximately:

**0.1885 m**

The required wheel rotations per second are:

**0.978 ÷ 0.1885 ≈ 5.19 rotations/s**

Converting to RPM:

**5.19 × 60 ≈ 311 RPM**

Therefore:

**Theoretical Wheel Speed ≈ 311 RPM**

---

## 5. Theoretical Speed at 80%

For the second theoretical calculation, a three-lap time of approximately:

**32 seconds**

was used.

Linear speed:

**26.4 ÷ 32**

**≈ 0.825 m/s**

Therefore, the theoretical average linear speed is:

**≈ 0.825 m/s**

---

## 6. Theoretical Wheel RPM at 80%

Using the same wheel circumference:

**0.825 ÷ 0.1885 ≈ 4.38 rotations/s**

Converting to RPM:

**4.38 × 60 ≈ 263 RPM**

Therefore:

**Theoretical Wheel Speed ≈ 263 RPM**

---

## Calculation Summary

| Calculation | 100% | 80% |
|---|---:|---:|
| Estimated 3-Lap Distance | 26.4 m | 26.4 m |
| Target Time | 27 s | 32 s |
| Linear Speed | ~0.978 m/s | ~0.825 m/s |
| Wheel Circumference | ~0.1885 m | ~0.1885 m |
| Wheel Speed | ~311 RPM | ~263 RPM |

---

## Assumptions

These calculations are theoretical estimates.

They assume:

- a wheel radius of 30 mm
- no wheel slip
- constant average speed
- a 1:1 effective drivetrain ratio
- no significant drivetrain losses

In real operation, acceleration, braking, turning, wheel slip, drivetrain resistance and motor loading affect the vehicle's actual speed.

For this reason, these calculations are used as an engineering reference rather than as measured performance data.

---

## Recorded Performance

During testing, NEO has completed one lap of the mat in approximately:

**8.7 seconds**

This is an observed result and is therefore documented separately from the theoretical calculations above.

<!-- UPLOAD HERE: Photo of handwritten mobility calculations -->

<!-- OPTIONAL: Upload a screenshot/photo showing the recorded lap timing -->

---

[← Back to Main README](../README.md)

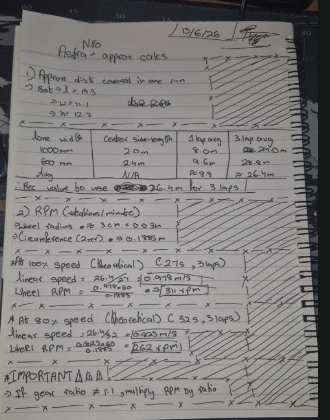
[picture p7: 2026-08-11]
other/Screenshot 2026-08-11 200621.png

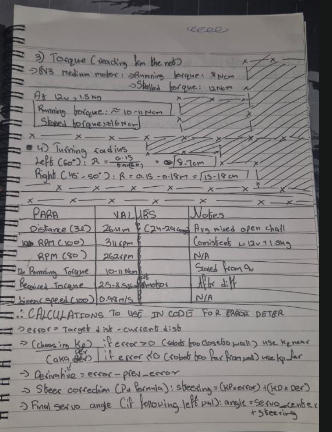
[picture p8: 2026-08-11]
other/Screenshot 2026-08-11 200631.png

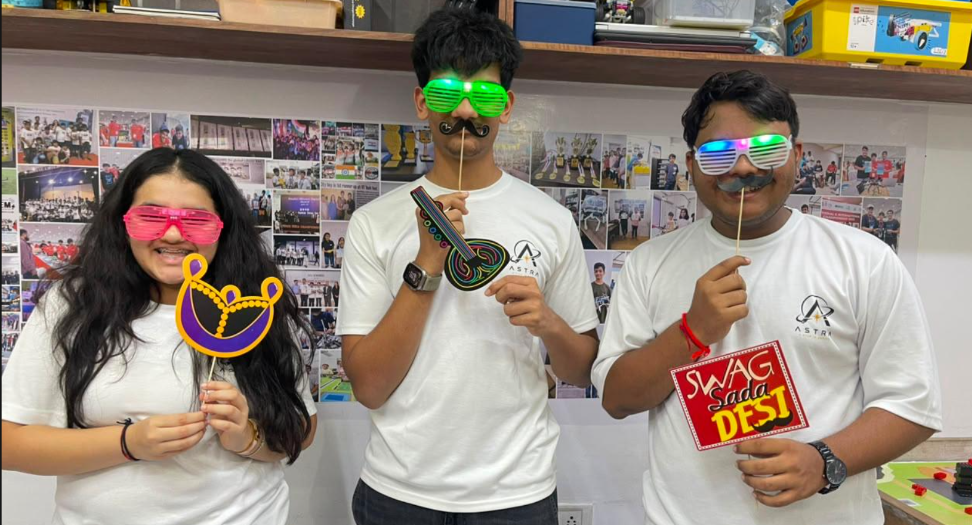
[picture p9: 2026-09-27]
t-photos/team_fun_photo.png

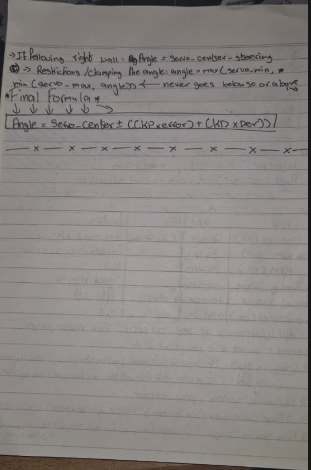
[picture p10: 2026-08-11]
other/Screenshot 2026-08-11 200635.png

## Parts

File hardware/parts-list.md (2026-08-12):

# NEO — Parts List / Bill of Materials

This page documents the main mechanical, electronic, sensing, power and custom-manufactured components used to build NEO.

NEO combines **LEGO Technic components**, **Raspberry Pi-based electronics** and **custom 3D-printed PLA parts**.

---

# Main Electronics

| Component | Quantity | Purpose |
|---|---:|---|
| Raspberry Pi 5 | 1 | Main controller for autonomous navigation and processing |
| Raspberry Pi Camera 3 Wide | 1 | Computer-vision input |
| TB6612FNG Motor Driver | 1 | Controls the LEGO EV3 Medium Motor |
| PCA9685 16-Channel PWM Controller | 1 | Generates PWM signals for steering control |
| TCA9548A 8-Channel I²C Multiplexer | 1 | Manages communication between multiple I²C devices |
| Push Button | 1 | Physical control input |

<!-- UPLOAD HERE: Photo showing NEO's main electronic components -->

---

# Motors & Drivetrain

| Component | Quantity | Purpose |
|---|---:|---|
| LEGO EV3 Medium Motor | 1 | Rear-wheel propulsion |
| SG90 Micro Servo | 1 | Front-wheel steering |
| LEGO Differential | 1 | Allows the rear wheels to rotate at different speeds while cornering |
| LEGO Technic Gears | As required | Transfers mechanical power through the drivetrain |
| LEGO Technic Axles | As required | Transfers rotation through the drivetrain |
| Wheels | 4 | Vehicle movement and traction |

NEO uses a **rear-wheel-drive configuration**, with the EV3 Medium Motor driving the rear axle through the LEGO differential.

[View NEO's drivetrain](../mobility/drivetrain.md)

[View NEO's steering system](../mobility/steering.md)

---

# Sensors

| Component | Quantity | Purpose |
|---|---:|---|
| VL53L5X ToF Sensor | As installed | Multi-zone distance measurement |
| ToF Laser Ranging Sensors | As installed | Front, side and rear proximity measurement |
| BNO055 IMU | Development component | Orientation and heading sensing during development |

The BNO055 was explored during development but is **not currently installed in NEO's present physical configuration**.

[View NEO's sensor system](sensors.md)

---

# Power System

| Component | Quantity | Purpose |
|---|---:|---|
| Bonka 11.1 V 2200 mAh LiPo Battery | 1 | Main power source |
| XL4015 5 V 5 A Buck Converter | 1 | Regulates power for the Raspberry Pi 5 |
| MP1584 3 A DC-DC Buck Converter | 1 | Regulates power for the motor electronics |
| iMAX B6AC Dual Power 80 W | 1 | LiPo balance charger |

The battery has a nominal energy capacity of approximately:

**11.1 V × 2.2 Ah = 24.4 Wh**

[View NEO's electrical system](electrical-system.md)

---

# Mechanical Construction

| Component | Quantity | Purpose |
|---|---:|---|
| LEGO Technic Beams & Structural Components | As required | Main mechanical construction |
| LEGO Technic Connectors & Pins | As required | Structural connections |
| LEGO Differential Gears | As required | Rear differential assembly |
| LEGO Axles | As required | Drivetrain and wheel connections |
| Custom 3D-Printed Components | 6 | Chassis, steering and camera-support structures |

The combination of LEGO Technic and custom 3D printing allows NEO to remain modular while providing purpose-built components where standard LEGO geometry is not sufficient.

---

# Custom 3D-Printed Parts

NEO uses **six custom-designed components**, manufactured in PLA using a **Bambu Lab A1**.

| Part | Purpose |
|---|---|
| FE2026 Custom Chassis | Structural platform for integrating NEO's mechanical and electronic systems |
| Servo Stand | Securely positions the SG90 steering servo |
| Servo Horn – 13 mm | Transfers servo rotation to the steering mechanism |
| Pi Camera 3 Mount | Holds the Raspberry Pi Camera 3 Wide |
| Camera Stand V2 | Earlier version of the elevated camera-support structure |
| Camera Stand V3 | Refined version of the camera-support structure |

### Manufacturing Information

| Parameter | Specification |
|---|---|
| Printer | Bambu Lab A1 |
| Material | PLA |
| Process | FDM 3D Printing |
| Number of Custom Parts | 6 |

<!-- UPLOAD HERE: Photograph of all six printed components -->

[View all 3D models and STL files](../3d-models/README.md)

---

# Component Selection

The components used in NEO were selected according to the requirements of an autonomous competition vehicle.

| Component | Why We Chose It |
|---|---|
| Raspberry Pi 5 | Provides the processing capability required for computer vision and autonomous navigation |
| Pi Camera 3 Wide | Wide field of view provides greater visual coverage of the competition field |
| LEGO EV3 Medium Motor | Compact and integrates easily with the LEGO drivetrain |
| SG90 Micro Servo | Compact and lightweight solution for controlled steering |
| TB6612FNG | Provides an interface between the controller and drive motor |
| LEGO Differential | Allows the driven rear wheels to rotate at different speeds during turns |
| VL53L5X / ToF Sensors | Provide direct distance information for navigation and parking |
| TCA9548A | Allows multiple I²C devices to be organised across selectable channels |
| PCA9685 | Provides dedicated PWM generation for servo control |
| XL4015 | Provides the regulated supply required by the Raspberry Pi |
| MP1584 | Provides a separate regulated supply for motor electronics |
| 11.1 V 2200 mAh LiPo | Compact main energy source for the vehicle |
| LEGO Technic | Provides modular mechanical construction |
| Custom PLA Parts | Allow components to be designed specifically around NEO's geometry |

---

# Component Integration

The major components interact through the following architecture:

**SENSING**

Pi Camera 3 Wide + ToF Sensors

↓

**PROCESSING**

Raspberry Pi 5

↓

**CONTROL**

PCA9685 + TB6612FNG

↓

**ACTUATION**

SG90 Servo + LEGO EV3 Medium Motor

↓

**MECHANICAL OUTPUT**

Front Steering + Rear-Wheel Drive

The complete system is powered by the **11.1 V LiPo battery** through separate regulated power paths.

<!-- UPLOAD HERE: Labelled photograph of NEO identifying the major components -->

---

# Parts List Summary

NEO's construction combines four main groups of components:

1. **Mechanical** — LEGO Technic, drivetrain, differential and wheels
2. **Electronic** — Raspberry Pi 5, motor driver, PWM controller and I²C multiplexer
3. **Sensing** — Pi Camera 3 Wide and Time-of-Flight sensors
4. **Custom Manufactured** — six 3D-printed PLA components

This modular approach allows individual systems to be replaced, repositioned and refined as NEO develops.

---

[← Back to Main README](../README.md)

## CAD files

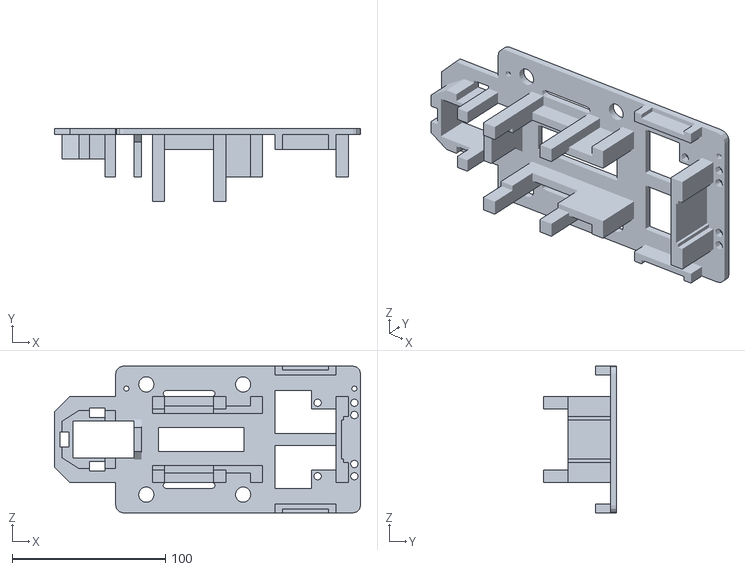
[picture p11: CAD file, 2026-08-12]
3d-models/fe2026_chassis_1st.stl
200.0 x 48.0 x 96.0

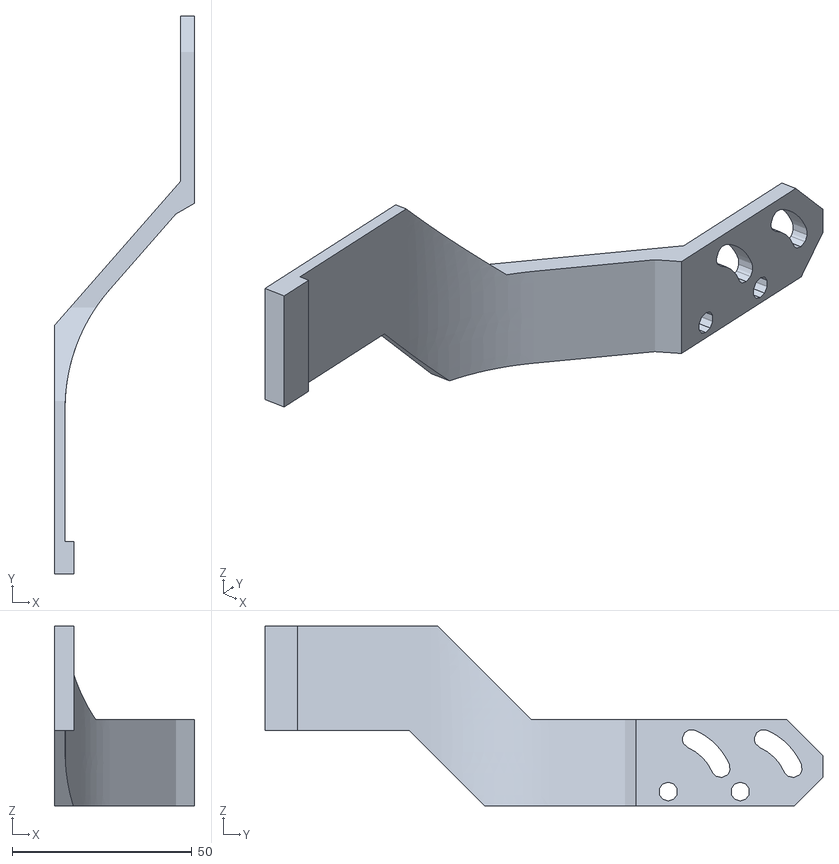
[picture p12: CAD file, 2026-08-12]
3d-models/camerastandv2.stl
39.0 x 155.0 x 50.0

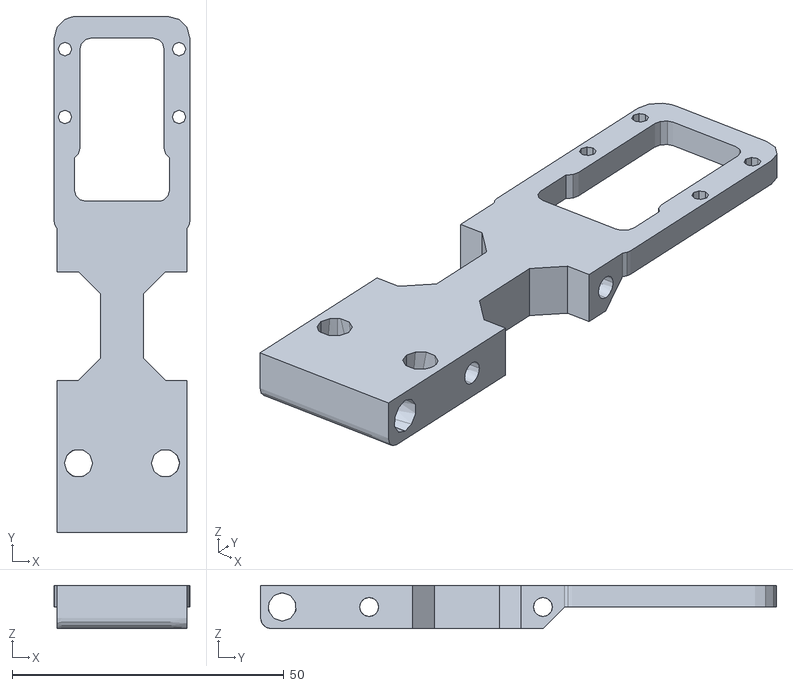
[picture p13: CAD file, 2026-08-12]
3d-models/picam3mount.stl
25.0 x 95.0 x 8.00

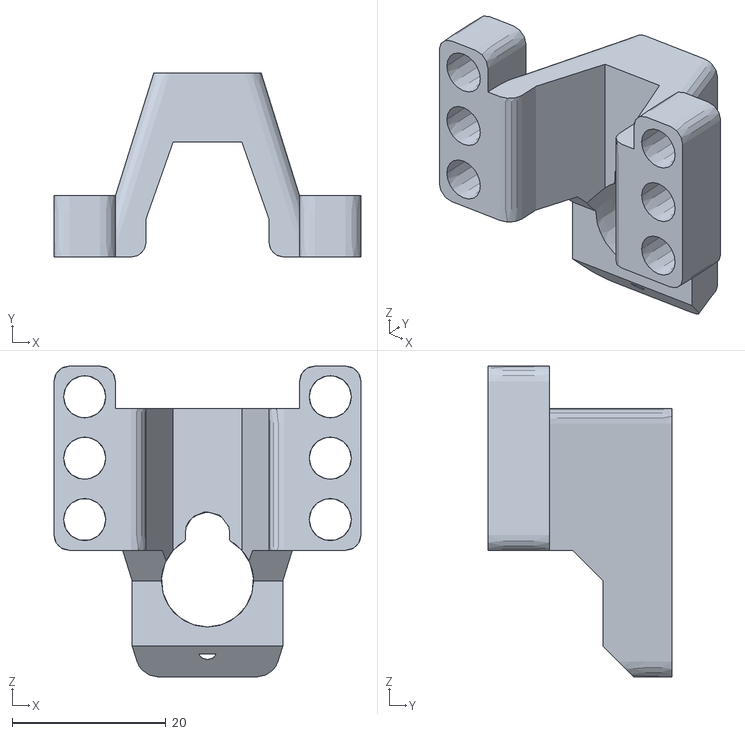
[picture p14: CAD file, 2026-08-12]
3d-models/wro_fe2026_servostand.stl
40.0 x 24.0 x 40.5

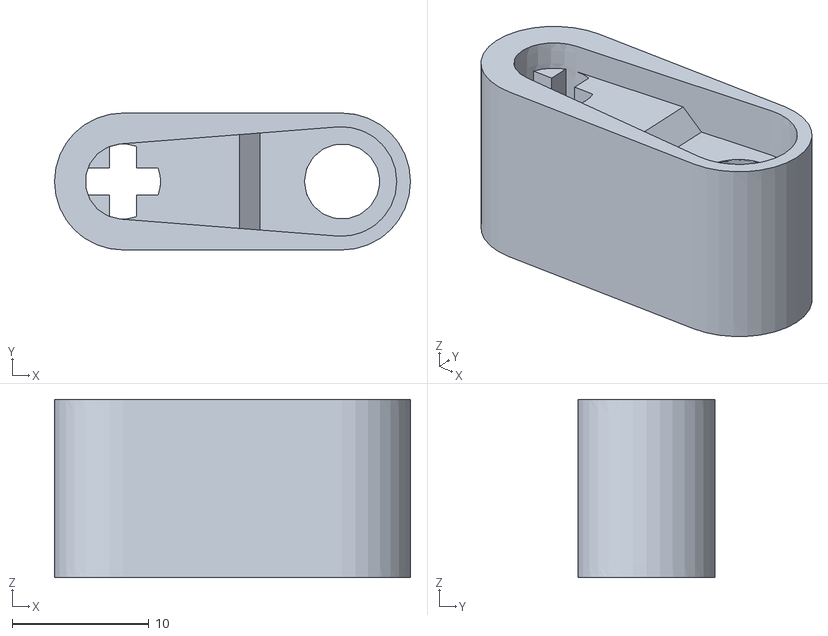
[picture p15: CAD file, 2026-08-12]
3d-models/wro_fe2026_servohorn13mm.stl
26.0 x 10.0 x 13.0

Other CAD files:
3d-models/camerastandv3.stl

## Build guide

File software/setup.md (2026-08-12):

# NEO — Raspberry Pi 5 Setup

NEO uses a **Raspberry Pi 5** as its main computing platform.

The Raspberry Pi runs the software required for computer vision, sensor processing, steering control, motor control and autonomous navigation.

This page documents the general setup process for preparing the Raspberry Pi to run NEO's software.

---

## Setup Overview

The general setup process is:

```text
Prepare Raspberry Pi
        ↓
Install / Configure Raspberry Pi OS
        ↓
Update System
        ↓
Create Python Environment
        ↓
Install Required Libraries
        ↓
Enable Hardware Interfaces
        ↓
Connect Camera & Sensors
        ↓
Test Steering
        ↓
Test Motor
        ↓
Run Autonomous Software
```

---

# Hardware Required

The Raspberry Pi setup requires:

- Raspberry Pi 5
- microSD card
- Raspberry Pi Camera 3 Wide
- ToF distance sensors
- TCA9548A I²C Multiplexer
- PCA9685 PWM Controller
- TB6612FNG Motor Driver
- SG90 Micro Servo
- LEGO EV3 Medium Motor
- suitable power supply during initial setup

During normal operation, the Raspberry Pi is powered through NEO's onboard regulated power system.

[View NEO's electrical system](../hardware/electrical-system.md)

---

# Operating System

NEO uses **Raspberry Pi OS** as the operating environment for the Raspberry Pi 5.

The operating system provides the software platform required to:

- run Python
- access the camera
- communicate with sensors
- communicate with control electronics
- run OpenCV
- execute NEO's autonomous programs

<!-- UPDATE HERE: Add exact Raspberry Pi OS version used on final competition robot -->

---

# Update the Raspberry Pi

After Raspberry Pi OS has been configured, update the available packages:

```bash
sudo apt update
sudo apt upgrade
```

This ensures that the system packages are up to date before the project dependencies are installed.

---

# Python Environment

NEO's main autonomous software is written in **Python**.

The installed Python version can be checked using:

```bash
python3 --version
```

<!-- UPDATE HERE: Add exact Python version used on final competition robot -->

---

# Create a Virtual Environment

A Python virtual environment can be used to keep NEO's project libraries separate from the Raspberry Pi's system Python installation.

Create a virtual environment:

```bash
python3 -m venv neo-env
```

Activate it:

```bash
source neo-env/bin/activate
```

Once activated, the libraries required by NEO can be installed inside this environment.

---

# Required Software

NEO's software environment includes libraries required for:

- computer vision
- camera access
- I²C communication
- ToF distance sensing
- PCA9685 control
- hardware communication
- numerical processing

Important software includes:

- Python
- OpenCV
- Raspberry Pi camera libraries
- I²C support
- ToF sensor libraries
- PCA9685 control libraries

<!-- UPDATE HERE: Add exact requirements.txt / package list from final software -->

---

# OpenCV

NEO uses **OpenCV** for computer-vision processing.

OpenCV is responsible for operations including:

- image processing
- colour conversion
- colour masking
- contour detection
- object localisation
- obstacle recognition

The OpenCV installation can be checked in Python using:

```python
import cv2

print(cv2.__version__)
```

[View NEO's computer-vision system](vision.md)

---

# Enable I²C

NEO uses I²C communication for several sensors and control devices.

Open the Raspberry Pi configuration utility:

```bash
sudo raspi-config
```

Enable **I²C** through the interface settings.

After I²C is enabled, compatible devices can communicate with the Raspberry Pi.

---

# Check I²C Devices

Connected I²C devices can be checked using:

```bash
i2cdetect -y 1
```

The resulting table can help confirm whether connected electronics are visible to the Raspberry Pi.

This is useful when checking:

- TCA9548A
- PCA9685
- ToF sensors
- other compatible I²C hardware

---

# TCA9548A Setup

NEO uses a **TCA9548A 8-channel I²C multiplexer** to manage multiple I²C devices.

The communication architecture is:

```text
Raspberry Pi 5
      ↓
     I²C
      ↓
   TCA9548A
      ↓
Individual I²C Channels
      ↓
Connected Sensors
```

The required channel is selected before communicating with a sensor connected through the multiplexer.

[View NEO's sensor system](../hardware/sensors.md)

---

# Camera Setup

NEO uses the **Raspberry Pi Camera 3 Wide**.

The camera connects directly to the Raspberry Pi through the CSI interface.

Before running the complete autonomous software, confirm that:

- the camera is detected
- frames can be captured
- the image orientation is correct
- the image is stable
- the required competition-field area is visible

<!-- UPLOAD HERE: Screenshot of successful camera test -->

The final camera height and angle will be documented after the physical camera position is fixed.

---

# Camera Processing

The camera is used together with Python and OpenCV.

The general software pipeline is:

```text
Pi Camera 3 Wide
        ↓
Capture Frame
        ↓
Raspberry Pi 5
        ↓
OpenCV Processing
        ↓
Visual Information
        ↓
Navigation Logic
```

[View NEO's vision system](vision.md)

---

# ToF Sensor Setup

NEO uses Time-of-Flight sensors to measure surrounding distances.

The sensors provide information from:

- front-left
- front-centre
- front-right
- rear

The general communication path is:

```text
ToF Sensor
     ↓
    I²C
     ↓
TCA9548A
     ↓
Raspberry Pi 5
```

Each sensor should be checked individually before the complete autonomous program is run.

[View NEO's sensor system](../hardware/sensors.md)

---

# PCA9685 Setup

NEO uses the **PCA9685 16-channel PWM controller** to generate the PWM signal required by the SG90 steering servo.

The communication path is:

```text
Raspberry Pi 5
      ↓
     I²C
      ↓
    PCA9685
      ↓
     PWM
      ↓
SG90 Micro Servo
```

Before autonomous testing, confirm that the PCA9685 is detected and that the servo responds correctly.

---

# Steering Setup

The SG90 servo should be calibrated before autonomous operation.

The calibration process includes:

1. Determine the servo centre position.
2. Align the front wheels approximately straight.
3. Test a small left steering movement.
4. Test a small right steering movement.
5. Determine safe software limits.
6. Store the calibrated values in the control software.

NEO's currently observed physical steering range is approximately:

| Direction | Approximate Maximum |
|---|---:|
| Left | ~60° |
| Right | Slightly above 45° |

These values will be replaced with precise measurements after final calibration.

[View NEO's steering system](../mobility/steering.md)

---

# Motor Setup

NEO's propulsion system consists of:

```text
Raspberry Pi 5
      ↓
  TB6612FNG
      ↓
LEGO EV3 Medium Motor
      ↓
LEGO Differential
      ↓
Rear Wheels
```

Before autonomous operation:

1. Check the motor-driver connections.
2. Ensure the drivetrain can rotate freely.
3. Perform an initial low-speed motor test.
4. Confirm the required motor direction.
5. Verify that the motor stops correctly.
6. Proceed to controlled driving tests.

[View NEO's drivetrain](../mobility/drivetrain.md)

---

# Recommended Hardware Test Order

Rather than immediately running the complete autonomous system, NEO's hardware should be checked progressively.

```text
Raspberry Pi
      ↓
Camera
      ↓
I²C Communication
      ↓
ToF Sensors
      ↓
PCA9685
      ↓
SG90 Servo
      ↓
TB6612FNG
      ↓
EV3 Medium Motor
      ↓
Integrated Autonomous System
```

Testing individual systems first makes faults easier to identify.

---

# Software Calibration

Once all hardware is communicating correctly, the autonomous software can be calibrated.

Important adjustable parameters can include:

- camera colour thresholds
- obstacle-detection thresholds
- minimum contour size
- steering centre
- steering limits
- proportional steering gain
- ToF distance thresholds
- motor commands
- emergency-response thresholds

These values can be refined during testing on the competition field.

---

# Running NEO

Activate the virtual environment:

```bash
source neo-env/bin/activate
```

Navigate to the folder containing NEO's software.

The relevant autonomous program can then be launched using Python.

For example:

```bash
python3 main.py
```

<!-- UPDATE HERE: Replace main.py with the exact final competition program/file name -->

---

# Troubleshooting

## Camera Not Detected

Check:

- camera ribbon cable
- cable orientation
- CSI connection
- camera configuration
- whether another process is using the camera

---

## I²C Device Not Detected

Check:

- device power
- SDA connection
- SCL connection
- common ground
- I²C configuration
- TCA9548A channel selection

---

## ToF Sensor Not Responding

Check:

- sensor power
- I²C wiring
- multiplexer channel
- software initialisation
- sensor connection

---

## Servo Not Responding

Check:

- PCA9685 communication
- servo connection
- servo power
- PWM channel
- common ground
- software steering command

---

## Motor Not Responding

Check:

- TB6612FNG connections
- motor-power supply
- control signals
- motor wiring
- drivetrain movement
- software motor command

---

# Final Competition Environment

Once NEO's competition software is finalised, Team Astra will document the exact environment used on the robot.

The final information should include:

| Item | Final Version |
|---|---|
| Raspberry Pi OS | To be confirmed |
| Python | To be confirmed |
| OpenCV | To be confirmed |
| Camera Libraries | To be confirmed |
| ToF Libraries | To be confirmed |
| PCA9685 Libraries | To be confirmed |
| Main Program | To be confirmed |

<!-- UPDATE HERE: Complete this table once the final software environment is frozen -->

Recording the final environment will make NEO's software configuration easier to understand and reproduce.

---

# Setup Summary

NEO's Raspberry Pi setup follows a progressive process:

```text
INSTALL
   ↓
CONFIGURE
   ↓
CONNECT
   ↓
TEST
   ↓
CALIBRATE
   ↓
INTEGRATE
   ↓
RUN
```

The Raspberry Pi 5 provides the central environment in which NEO's camera processing, sensor communication and autonomous-control software operate together.

---

[← Back to Main README](../README.md)

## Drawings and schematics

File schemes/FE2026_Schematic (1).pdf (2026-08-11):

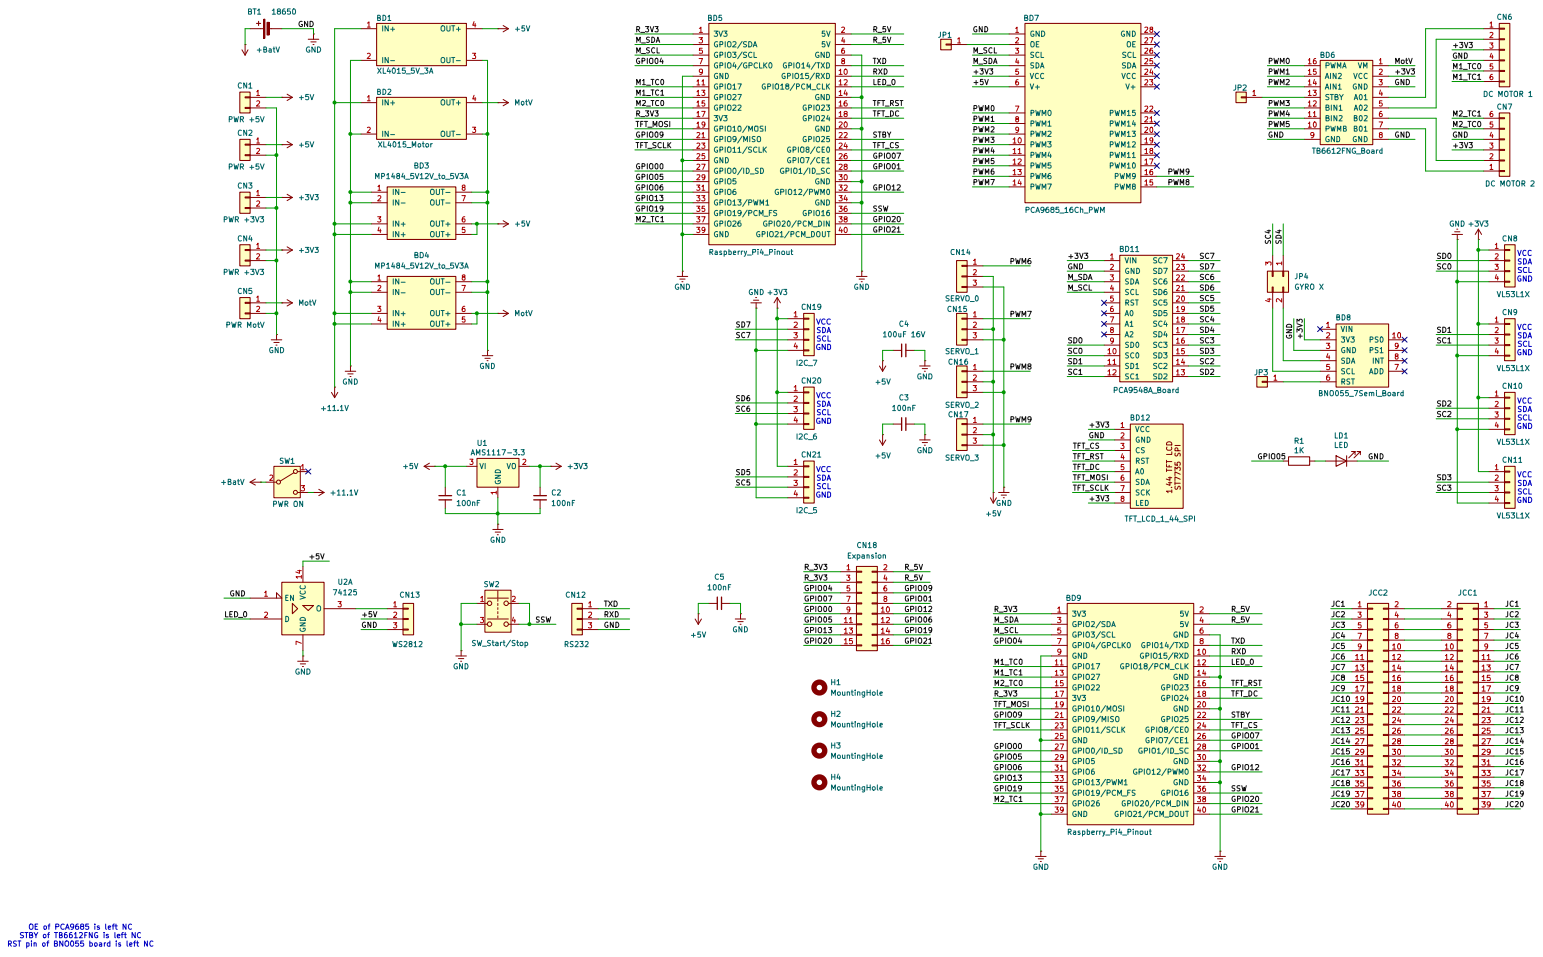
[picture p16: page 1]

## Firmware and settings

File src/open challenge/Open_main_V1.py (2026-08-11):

# Open_main_V2.py
# This WRO_OPEN working perfect with all positions Dt.02/08/2026
# Direction Detection = Gyro (Straight + Turn + Straight)
# Wall Following  = Using Sensor Left or Right
# Corner Counting = Using Left or Right Sensors
# Stop Section = Timer Base
# coding: UTF-8

import sys
import time
import smbus
import board
import busio

# Import our finalized hardware modules
import config
import camera
import motor
import servo
import tof_sensor
import bno055


from gpiozero import OutputDevice
from gpiozero import LED, Button  # Replaced RPi.GPIO with gpiozero

from adafruit_pca9685 import PCA9685
import subprocess
subprocess.run(["pinctrl", "set", "12", "a0"], check=True)
from rpi_hardware_pwm import HardwarePWM

sys.path.append("..")
import TOF_Sense_update_1

# ==========================================================
# PCA9548A
# ==========================================================

MUX_ADDR = 0x70

LEFT_CHANNEL = 5
FRONT_CHANNEL = 3
RIGHT_CHANNEL = 2

bus = smbus.SMBus(1)

def select_channel(channel):
    bus.write_byte(MUX_ADDR, 1 << channel)
    time.sleep(0.002)

tof = TOF_Sense_update_1.TOF_Sense(1)

def get_distance(channel):
    select_channel(channel)
    d = tof.get_distance()

    if d <= 0:
        return None

    return d

# ==========================================================
# Motor
# ==========================================================

stby = OutputDevice(6)
stby.on()

i2c = busio.I2C(board.SCL, board.SDA)

pca = PCA9685(i2c)

# Motor PWM
pca.frequency = 1000

# Servo Hardware PWM (GPIO12)
servo = HardwarePWM(
    pwm_channel=0,
    hz=50
)

servo.start(7.99)      # Center duty

PWMA = 0
AIN2 = 1
AIN1 = 2


# motor frequency
pca.frequency = 1000				####################

def set_pwm(ch, percent):
    percent = max(0, min(100, percent))
    pca.channels[ch].duty_cycle = int(percent * 65535 / 100)

def digital(ch, state):
    pca.channels[ch].duty_cycle = 65535 if state else 0

def motor_forward(speed):
    digital(AIN1, True)
    digital(AIN2, False)
    set_pwm(PWMA, speed)

def motor_stop():
    set_pwm(PWMA, 0)
    digital(AIN1, False)
    digital(AIN2, False)

# ==========================================================
# Servo
# ==========================================================

SERVO_MIN_US = 500
SERVO_MAX_US = 2400

SERVO_MIN = 50
SERVO_CENTER = 95
SERVO_MAX = 140

    
def angle_to_duty_percent(angle):

    angle = max(SERVO_MIN, min(SERVO_MAX, angle))

    pulse = SERVO_MIN_US + (
        angle / 180.0
    ) * (SERVO_MAX_US - SERVO_MIN_US)

    duty = pulse / 20000.0 * 100.0

    return duty


def set_servo(angle):

    servo.change_duty_cycle(
        angle_to_duty_percent(angle)
    )

# ==========================================================
# Wall Following Parameters
# ==========================================================

TARGET_DISTANCE = 180      # mm

KP_FAR = 0.30
KP_NEAR = 0.65
KD = 0.02

BASE_SPEED = 100

previous_error = 0

# ==========================================================
# Lap / Corner Counter
# ==========================================================

CORNER_THRESHOLD = 500      # left wall disappeared
FRONT_CORNER = 220          # approaching next wall
 
CORNER_HIGH = 550
CORNER_END = 300

corner_state = 0            # state machine
corner_count = 0

TOTAL_CORNERS = 11

finish_timer = None

# ==========================================================
# Main
# ==========================================================

try:
    set_servo(SERVO_CENTER)
    time.sleep(1)

    print("Initializing Gyro for Startup Sequence...")
    bno055.initialize()
    time.sleep(1) 
    
    target_heading = bno055.get_heading()
    if target_heading is None:
        target_heading = 0 
        
    print("Driving straight to determine initial direction...")
    motor_forward(BASE_SPEED)
    
    wall_direction = "LEFT" # Fallback default
    
    # Startup Loop
    while True:
        left = get_distance(LEFT_CHANNEL)
        right = get_distance(RIGHT_CHANNEL)
        current_heading = bno055.get_heading()
        
        # 1. Steer straight using Gyro
        if current_heading is not None and target_heading is not None:
            error_heading = target_heading - current_heading
            
            # Normalize error
            while error_heading <= -180: error_heading += 360
            while error_heading > 180: error_heading -= 360
                
            # Straight drive P-control
            gyro_kp = 0.8 
            steer_correction = gyro_kp * error_heading
            angle = SERVO_CENTER + steer_correction
            angle = max(SERVO_MIN, min(SERVO_MAX, angle))
            set_servo(angle)
            
        # 2. Check for open track direction
        if left is not None and right is not None:
            diff = abs(left - right)
            
            if diff > 1000:
                motor_stop()
                if left > right:
                    wall_direction = "LEFT"
                    turn_servo_angle = SERVO_MIN  # Full Left Lock
                    heading_change = -90          # Gyro shift for Left turn
                    print("Result: Left side open. Executing 90-deg LEFT turn.")
                else:
                    wall_direction = "RIGHT"
                    turn_servo_angle = SERVO_MAX  # Full Right Lock
                    heading_change = 90           # Gyro shift for Right turn
                    print("Result: Right side open. Executing 90-deg RIGHT turn.")
                time.sleep(0.5) 
                break # Exit direction-finding loop
                
        time.sleep(0.015)
        
    # ==========================================================
    # TRANSITION PHASE 1: 90-Degree Turn
    # ==========================================================
    current_heading = bno055.get_heading()
    if current_heading is not None:
        # Calculate target heading and handle 0-360 wrap around
        target_turn_heading = (current_heading + heading_change) % 360 
        
        set_servo(turn_servo_angle)
        motor_forward(BASE_SPEED) 
        
        while True:
            current = bno055.get_heading()
            if current is not None:
                # Calculate difference accounting for 360 wrap
                diff = current - target_turn_heading
                while diff <= -180: diff += 360
                while diff > 180: diff -= 360
                
                # Stop turning when within 5 degrees of the 90-deg target
                if abs(diff) < 5: 
                    break
            time.sleep(0.01)

    # ==========================================================
    # TRANSITION PHASE 2: Settle Parallel (2 Seconds Straight)
    # ==========================================================
    print("Turn complete. Driving straight to align with wall...")
    new_straight_heading = bno055.get_heading()
    straight_end_time = time.time() + 1.0  # Run for exactly 1 seconds
    
    while time.time() < straight_end_time:
        current = bno055.get_heading()
        if current is not None and new_straight_heading is not None:
            error_heading = new_straight_heading - current
            
            # Normalize error
            while error_heading <= -180: error_heading += 360
            while error_heading > 180: error_heading -= 360
                
            # Straight drive P-control
            gyro_kp = 0.8 
            steer_correction = gyro_kp * error_heading
            angle = SERVO_CENTER + steer_correction
            angle = max(SERVO_MIN, min(SERVO_MAX, angle))
            set_servo(angle)
            
        motor_forward(BASE_SPEED)
        time.sleep(0.015)

    print("Starting Main Wall Following...")
    previous_error = 0
    

    while True:

        left = get_distance(LEFT_CHANNEL)
        front = get_distance(FRONT_CHANNEL)
        right = get_distance(RIGHT_CHANNEL)
        
        # Assign dynamic sensor reading based on determined direction
        if wall_direction == "LEFT":
            if left is None: continue
            current_distance = left
        else:
            if right is None: continue
            current_distance = right
        
        # ----------------------------------------------------------
        # Corner Detection
        # ----------------------------------------------------------

        if current_distance is not None and front is not None:

            # State 0
            # Waiting until left wall disappears
            if corner_state == 0:

                if current_distance is not None and current_distance > CORNER_HIGH:
                    corner_state = 1


            # State 1
            # Wait until front wall appears
            elif corner_state == 1:

                if current_distance is not None and current_distance < CORNER_END:
                    corner_count += 1
                    print("Corner =", corner_count)
                    #print(f"\n***** CORNER {corner_count} *****\n")
                    corner_state = 2


            # State 2
            # Wait until robot is back following wall
            elif corner_state == 2:
                if current_distance is not None and abs(current_distance - TARGET_DISTANCE) < 30:
                    corner_state = 0

            

        # ----------------------------------------------------------
        # Finish after 12 corners
        # ----------------------------------------------------------

        if corner_count >= TOTAL_CORNERS:

            if finish_timer is None:
                finish_timer = time.time()

            # continue following wall for 1 second
            elif time.time() - finish_timer >= 1.0:
                print("\nFinished 3 laps!")
                break
        
        
        if front is not None and front < 50:

            print("Obstacle Emergency STOP..!")
            motor_stop()
            # steer straight
            set_servo(SERVO_CENTER)
            break

        error = TARGET_DISTANCE - current_distance
        
        if error > 0:
            KP = KP_NEAR      # Robot is too close to the wall
        else:
            KP = KP_FAR       # Robot is too far from the wall

        derivative = error - previous_error

        steering = KP * error + KD * derivative

        previous_error = error

        # Apply steering (Invert the steering logic for the right wall)
        if wall_direction == "LEFT":
            angle = SERVO_CENTER + steering
        else:
            angle = SERVO_CENTER - steering

        angle = max(SERVO_MIN, min(SERVO_MAX, angle))

        set_servo(angle)

        motor_forward(BASE_SPEED)

        print(f"Left:{left:4}  Front:{front:4}  Right:{right:4}  Error:{error:5}  Servo:{angle:6.1f} Corner:{corner_count:2}")
    
        time.sleep(0.015)

except KeyboardInterrupt:

    print("Stopping...")

finally:

    motor_stop()
    set_servo(SERVO_CENTER)
    servo.stop()
    stby.off()
    pca.deinit()

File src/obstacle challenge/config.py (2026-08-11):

import numpy as np

# ==========================================
# Hardware Configuration (Servo)
# ==========================================
SERVO_PWM_CHANNEL = 0
SERVO_FREQUENCY = 50
SERVO_MIN_US = 500
SERVO_MAX_US = 2400
SERVO_MIN = 50
SERVO_CENTER = 95
SERVO_MAX = 140

# Original fallback servo limits (retained for compatibility)
CALIBRATED_MIN_PW_S = 0.001
CALIBRATED_MAX_PW_S = 0.002
CALIBRATED_ANGLE_MIN = 45.0
CALIBRATED_ANGLE_MAX = 135.0
INPUT_ANGLE_MIN_SERVO = -45.0
INPUT_ANGLE_MAX_SERVO = 45.0
SAFETY_MIN_PW_S = 0.001
SAFETY_MAX_PW_S = 0.0021
SERVO_PWM_PERIOD_S = 1.0 / SERVO_FREQUENCY

# ==========================================
# Hardware Configuration (Motor)
# ==========================================
MOTOR_PWM_CHANNEL = 0
MOTOR_IN1_CHANNEL = 2
MOTOR_IN2_CHANNEL = 1
MOTOR_PWM_FREQUENCY = 1000
STBY_PIN = 6

OPEN_BASE_SPEED = 50
OBS_BASE_SPEED = 85
MAX_SPEED = 95
CORNERING_SPEED = 30
DODGE_SPEED = 30
DRIVE_SPEED = 100.0  # Retained from original config

# ==========================================
# MUX & TOF Sensor Configuration
# ==========================================
MUX_ADDR = 0x70
LEFT_CHANNEL = 5
FRONT_CHANNEL = 3
RIGHT_CHANNEL = 2
GYRO_CHANNEL = 4

TOF_ENABLED = True
TOF_CHANNELS_TO_USE = range(1,4)
TOF_FORWARD_SENSOR_CHANNEL = 1
TOF_CORNERING_THRESHOLD_MM = 240
TOF_OBSTACLE_THRESHOLD_MM = 100

# ==========================================
# Gyroscope & Steering Variables
# ==========================================
GYRO_ENABLED = True
GYRO_KP = 0.5
HEADING_LOCK_TOLERANCE = 5.0
TILT_THRESHOLD_DEGREES = 15.0

MAX_CENTERING_ANGLE = 25
KP_CENTERING = 0.05
KP_STEERING = 0.3
WALL_FOLLOW_KP = 0.2

AVOIDANCE_OFFSET = 300
SAFE_RED_X_MAX = 200         
SAFE_GREEN_X_MIN = 440       

# ==========================================
# Camera & Vision Settings
# ==========================================
FRAME_WIDTH = 640
FRAME_HEIGHT = 480
MAX_FPS = 30
CROP_TOP_FRAC = 5 / 12
CROP_BOTTOM_FRAC = 0

MIN_CONTOUR_AREA = 2500
MAX_BLOCK_AREA_FRACTION = 0.25
MIN_BLOCK_AREA_FOR_ACTION = 7500 
MIN_BLOCK_ROI_OVERLAP = 0.50

BOX_COLOR_RED = (0, 0, 255)
BOX_COLOR_GREEN = (0, 255, 0)
BOX_COLOR_ROI = (255, 0, 255)

# HSV Color Thresholds
LOWER_RED_1 = np.array([0, 150, 40])
UPPER_RED_1 = np.array([10, 255, 200])
LOWER_RED_2 = np.array([175, 150, 40])
UPPER_RED_2 = np.array([180, 255, 200])

LOWER_GREEN = np.array([36, 50, 35])
UPPER_GREEN = np.array([89, 255, 130])

ORANGE_LOWER = np.array([6, 70, 20])				
ORANGE_UPPER = np.array([26, 255, 255])				

BLUE_LOWER = np.array([94, 45, 58])					
BLUE_UPPER = np.array([140, 226, 185])	

# ==========================================
# Dynamic Flow & Maneuver Variables
# ==========================================
TOTAL_TURNS = 12
TOTAL_CORNERS = 12           
LOOP_DELAY = 0.03
MIN_FRAMES_IN_TURN = 30      

EMERGENCY_STOP_DISTANCE = 50
FRONT_DODGE_THRESHOLD = 50
MIN_WALL_DIST_MM = 150       
TOF_BLOCK_CLEARED_MM = 400   

CORNER_AREA_THRESHOLD = 5000  
CORNER_COOLDOWN = 2.0         
CORNER_SPEED = 30             

MANEUVER_ANGLE_DEG = 45.0
MANEUVER_DRIVE_FRAMES_SIDEWAYS = 10
MANEUVER_DRIVE_FRAMES_STRAIGHT = 0
SPECIAL_TURN_SIDEWAYS_FRAMES = 0

CCW_TURN_ANGLE = 90.0
CCW_SCAN_ANGLE = 60.0
CCW_NORMAL_DRIVE_FRAMES = 25
CCW_REVERSE_FRAMES = 10
CCW_SHORT_DRIVE_FRAMES = 0

CW_DRIVE_FORWARD_RED_FRAMES = 25
CW_REVERSE_GREEN_FRAMES = 15
CW_DRIVE_FORWARD_NONE_FRAMES = 0

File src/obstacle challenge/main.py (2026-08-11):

# main.py
# This code is working with clockwise direction only Dt.07/08/2026

from collections import deque
import time
import queue
import numpy as np
import cv2
import threading
import os
import sys
import traceback
from datetime import datetime
from gpiozero import Button, LED

# --- FLAT DIRECTORY IMPORTS ---
import bno055
import camera
import distance
import motor
import servo
import config

ORANGE_COOLDOWN_FRAMES = 50
ORANGE_DETECTION_HISTORY_LENGTH = 4

#WALL_THRESHOLD = 200

FRAME_WIDTH = 640
FRAME_HEIGHT = 360
FRAME_MIDPOINT_X = FRAME_WIDTH // 2

#USE_LAB = False

HSV_RANGES = {
    'LOWER_RED_1': np.array([0, 100, 55]), 'UPPER_RED_1': np.array([5, 255, 255]),
    'LOWER_RED_2': np.array([174, 100, 55]), 'UPPER_RED_2': np.array([180, 255, 255]),
    'LOWER_GREEN': np.array([40, 108, 40]), 'UPPER_GREEN': np.array([80, 255, 180]),
    'LOWER_BLACK': np.array([0, 0, 0]), 'UPPER_BLACK': np.array([180, 95, 70]),
    'LOWER_ORANGE': np.array([6, 70, 20]), 'UPPER_ORANGE': np.array([26, 255, 255]),
    'LOWER_MAGENTA': np.array([158, 73, 64]), 'UPPER_MAGENTA': np.array([172, 255, 223]),
    'LOWER_BLUE': np.array([94, 45, 58]), 'UPPER_BLUE': np.array([140, 226, 185])
}

COLOR_RANGES = HSV_RANGES

LOWER_RED_1 = COLOR_RANGES['LOWER_RED_1']
UPPER_RED_1 = COLOR_RANGES['UPPER_RED_1']
LOWER_RED_2 = COLOR_RANGES['LOWER_RED_2']
UPPER_RED_2 = COLOR_RANGES['UPPER_RED_2']
LOWER_GREEN = COLOR_RANGES['LOWER_GREEN']
UPPER_GREEN = COLOR_RANGES['UPPER_GREEN']
LOWER_BLACK = COLOR_RANGES['LOWER_BLACK']
UPPER_BLACK = COLOR_RANGES['UPPER_BLACK']
LOWER_ORANGE = COLOR_RANGES['LOWER_ORANGE']
UPPER_ORANGE = COLOR_RANGES['UPPER_ORANGE']
LOWER_MAGENTA = COLOR_RANGES['LOWER_MAGENTA']
UPPER_MAGENTA = COLOR_RANGES['UPPER_MAGENTA']
LOWER_BLUE = COLOR_RANGES['LOWER_BLUE']
UPPER_BLUE = COLOR_RANGES['LOWER_BLUE']

detection_params = {'min_area': 300, 'return_rule': 'biggest_in_job', 'return_mask': True}
WALL_MIN_AREA = detection_params['min_area']
BLOCK_MIN_AREA = 500
MAGENTA_MIN_AREA = 500
CLOSE_BLOCK_MIN_AREA = 15

left_roi_x, left_roi_y, left_roi_w, left_roi_h = 0, 140, 135, 150
right_roi_x, right_roi_y, right_roi_w, right_roi_h = 505, 140, 135, 150
inner_left_roi_x, inner_left_roi_y, inner_left_roi_w, inner_left_roi_h = 140, 165, 100, 100
inner_right_roi_x, inner_right_roi_y, inner_right_roi_w, inner_right_roi_h = 400, 165 , 100, 100
line_roi_x, line_roi_y, line_roi_w, line_roi_h = 280, 200, 80, 40
close_x,close_y,close_w,close_h = 140,120,360,10
full_frame_roi = (0, 100, 640, 165)
close_block_roi = (250, 230, 140, 10)

left_side_job = {'roi': (left_roi_x, left_roi_y, left_roi_w, left_roi_h), 'type': 'wall_left'}
right_side_job = {'roi': (right_roi_x, right_roi_y, right_roi_w, right_roi_h), 'type': 'wall_right'}
inner_left_side_job = {'roi': (inner_left_roi_x, inner_left_roi_y, inner_left_roi_w, inner_left_roi_h), 'type': 'wall_inner_left'}
inner_right_side_job = {'roi': (inner_right_roi_x, inner_right_roi_y, inner_right_roi_w, inner_right_roi_h), 'type': 'wall_inner_right'}

roi_mask_walls = np.zeros((FRAME_HEIGHT, FRAME_WIDTH), dtype="uint8")
for job in [left_side_job, right_side_job, inner_left_side_job, inner_right_side_job]:
    x, y, w, h = job['roi']
    cv2.rectangle(roi_mask_walls, (x, y), (x + w, y + h), 255, -1)

roi_mask_main_blocks = np.zeros((FRAME_HEIGHT, FRAME_WIDTH), dtype="uint8")
x, y, w, h = full_frame_roi
cv2.rectangle(roi_mask_main_blocks, (x, y), (x + w, y + h), 255, -1)

roi_mask_close_blocks = np.zeros((FRAME_HEIGHT, FRAME_WIDTH), dtype="uint8")
x, y, w, h = close_block_roi
cv2.rectangle(roi_mask_close_blocks, (x, y), (x + w, y + h), 255, -1)

roi_mask_line = np.zeros((FRAME_HEIGHT, FRAME_WIDTH), dtype="uint8")
cv2.rectangle(roi_mask_line, (line_roi_x, line_roi_y), (line_roi_x + line_roi_w, line_roi_h + line_roi_y), 255, -1)

roi_mask_magenta = np.zeros((FRAME_HEIGHT, FRAME_WIDTH), dtype="uint8")
x, y, w, h = full_frame_roi
cv2.rectangle(roi_mask_magenta, (x, y), (x + w, y + h), 255, -1)

roi_mask_close_black = np.zeros((FRAME_HEIGHT, FRAME_WIDTH), dtype="uint8")
cv2.rectangle(roi_mask_close_black, (close_x, close_y), (close_x + close_w, close_y + close_h), 255, -1)

class CameraThread(threading.Thread):
    def __init__(self, camera_instance):
        super().__init__()
        self.camera = camera_instance
        self.latest_frame = None
        self.lock = threading.Lock()
        self.stop_event = threading.Event()
        self.daemon = True
        self.frame_counter = 0

    def run(self):
        while not self.stop_event.is_set():
            frame = self.camera.capture_frame()
            with self.lock:
                self.frame_counter += 1
                self.latest_frame = frame

    def get_frame(self):
        with self.lock:
            if self.latest_frame is not None:
                return self.latest_frame.copy(), self.frame_counter
            return None

    def stop(self):
        self.stop_event.set()

class VideoWriterThread(threading.Thread):
    def __init__(self, path, fourcc, fps, frame_size):
        super().__init__()
        self.out = cv2.VideoWriter(path, fourcc, fps, frame_size)
        self.queue = queue.Queue()
        self.stop_event = threading.Event()
        self.daemon = True

    def run(self):
        while not self.stop_event.is_set() or not self.queue.empty():
            try:
                frame = self.queue.get(timeout=0.1)
                self.out.write(frame)
                self.queue.task_done()
            except queue.Empty:
                continue
            except:
                print(f"VideoWriterThread: ERROR writing frame")
                traceback.print_exc()
                continue
        self.out.release()

    def write(self, frame):
        if not self.stop_event.is_set():
            self.queue.put(frame)

    def stop(self):
        self.stop_event.set()
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

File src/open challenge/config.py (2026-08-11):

import numpy as np
# ==========================================
# Servo Configuration
# ==========================================

SERVO_PWM_CHANNEL = 0
SERVO_FREQUENCY = 50
SERVO_MIN_US = 500
SERVO_MAX_US = 2400
SERVO_MIN = 50
SERVO_CENTER = 95
SERVO_MAX = 140
MAX_CENTERING_ANGLE = 25
KP_CENTERING = 0.05
GYRO_KP = 0.5


# ==========================================
# Motor Configuration
# ==========================================

MOTOR_PWM_CHANNEL = 0
MOTOR_IN1_CHANNEL = 2
MOTOR_IN2_CHANNEL = 1
MOTOR_PWM_FREQUENCY = 1000
STBY_PIN = 6
BASE_SPEED = 50
MAX_SPEED = 50
CORNERING_SPEED = 30
DODGE_SPEED = 30

# ==========================================
# TOF Sensor Configuration
# ==========================================

MUX_ADDR = 0x70
LEFT_CHANNEL = 5
FRONT_CHANNEL = 3
RIGHT_CHANNEL = 2
GYRO_CHANNEL = 4


# ==========================================
# Dynamic Steering & Flow Variables
# ==========================================
TOTAL_CORNERS = 12           # 3 Laps * 4 Corners
LOOP_DELAY = 0.03
MIN_FRAMES_IN_TURN = 30      # Frames to wait while shifting lanes

# Virtual Bumper & Clear Rules
EMERGENCY_STOP_DISTANCE = 50
FRONT_DODGE_THRESHOLD = 50
MIN_WALL_DIST_MM = 150       # Veto camera if wall is closer than 150mm
TOF_BLOCK_CLEARED_MM = 400   # Block is passed when side ToF reads > 400mm

# Proportional Camera Steering (X-Coordinates for Safe Passing)
SAFE_RED_X_MAX = 200         # Red block must be to the left of X=200
SAFE_GREEN_X_MIN = 440       # Green block must be to the right of X=440

AVOIDANCE_OFFSET = 300  	# Adjust this (in pixels) based on how wide your robot is
KP_STEERING = 0.3      		# Adjust this to make steering more/less aggressive

# ==========================================
# Camera & Vision Settings
# ==========================================
FRAME_WIDTH = 640
FRAME_HEIGHT = 480
MAX_FPS = 30
CROP_TOP_FRAC = 5 / 12
CROP_BOTTOM_FRAC = 0
MIN_CONTOUR_AREA = 2500
MAX_BLOCK_AREA_FRACTION = 0.25
MIN_BLOCK_AREA_FOR_ACTION = 7500 # Threshold to trigger Dodge State
MIN_BLOCK_ROI_OVERLAP = 0.50

# HSV Color Thresholds (Required for find_biggest_block)
LOWER_RED_1 = np.array([0, 150, 40])
UPPER_RED_1 = np.array([10, 255, 200])
LOWER_RED_2 = np.array([175, 150, 40])
UPPER_RED_2 = np.array([180, 255, 200])

LOWER_GREEN = np.array([36, 50, 35])
UPPER_GREEN = np.array([89, 255, 130])

# HSV Color ranges (Adjust these based on your track lighting!)
ORANGE_LOWER = np.array([6, 70, 20])				#([5, 150, 150])
ORANGE_UPPER = np.array([26, 255, 255])				#([15, 255, 255])

BLUE_LOWER = np.array([94, 45, 58])					#([100, 150, 150])
BLUE_UPPER = np.array([140, 226, 185])				#([120, 255, 255])

BOX_COLOR_RED = (0, 0, 255)
BOX_COLOR_GREEN = (0, 255, 0)

# --- Corner Detection Settings ---
CORNER_AREA_THRESHOLD = 5000  # Min pixels to trigger a turn (tune this!)
CORNER_COOLDOWN = 2.0         # Seconds to ignore lines after finishing a turn
CORNER_SPEED = 30             # Slow down a bit for sharp turns

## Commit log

2026-08-11 add fe pcb schematic
2026-08-12 Add mobility calculations documentation
    Document the theoretical calculations for NEO's wheel movement, speed, and RPM based on known values and assumptions.
2026-08-12 Document NEO's steering system and components
    Added detailed documentation for NEO's steering system, including architecture, components, and calibration procedures.
2026-08-12 Add parts list and specifications for NEO
    Documented the parts list and specifications for NEO, including electronics, motors, sensors, power system, mechanical construction, and custom 3D-printed parts.
2026-08-12 Create README for NEO 3D Models and Custom Parts
    Added comprehensive documentation for NEO's 3D models and custom parts, including manufacturing information, component descriptions, and STL file access.
2026-08-12 Add Raspberry Pi 5 setup documentation for NEO
    Document the setup process for NEO on Raspberry Pi 5, including hardware requirements, software installation, and troubleshooting steps.
